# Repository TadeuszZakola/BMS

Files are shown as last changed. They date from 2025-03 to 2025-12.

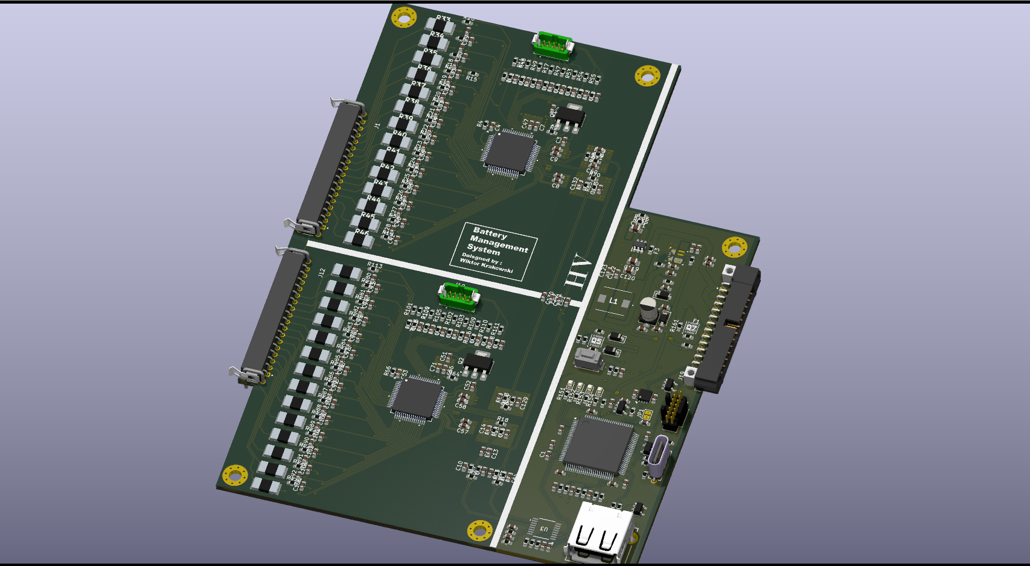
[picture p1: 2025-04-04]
bms.png

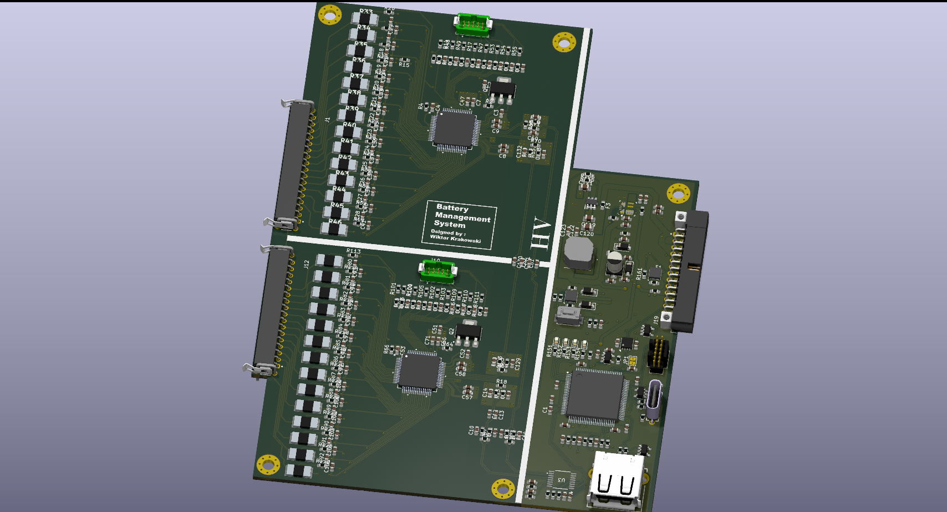
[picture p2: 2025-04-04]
bms2.png

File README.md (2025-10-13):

#Battery Management System  🔋⚡️

Welcome to the Battery Management System (BMS) project! 🚀 This open-source project combines cutting-edge hardware and software to deliver a robust, customizable solution for managing battery packs in applications like electric vehicles. With advanced monitoring, safety features, and seamless integration, this BMS ensures optimal battery performance and longevity. 🌱

🌟 Key Features

26 Individual Cell-Group Voltage Measurements ✅: Monitors voltage across 26 cell groups with high precision.

16 Temperature Sensors 🌡️: Provides comprehensive thermal monitoring to prevent overheating and ensure safe operation.

Cell Balancing 🔄: Actively balances cells to optimize capacity and extend battery lifespan.

Safety Relay 🔒: Isolates the battery pack during faults for enhanced safety.

Current Sensor ⚡: Enables real-time current monitoring and protection against overcurrent conditions.

CAN Bus 📊: Supports CAN communication for integration with external systems and data logging.

Advanced Safety Features 🛡️:

Over-voltage and under-voltage protection

Over-temperature shutdown

Current limiting via relay and BMS logic

Emergency cut-off for driver safety

Hardware & Software Integration 🛠️: Combines robust hardware (microcontroller, sensors, relays) with modular software for real-time monitoring and control.

User-Friendly Dashboard App 🖥️: Visualize battery metrics and configure settings through an intuitive interface.

CAN Integration: Supports CAN bus protocols for data transmission and external control.

Logging: Stores historical data for diagnostics and performance analysis.

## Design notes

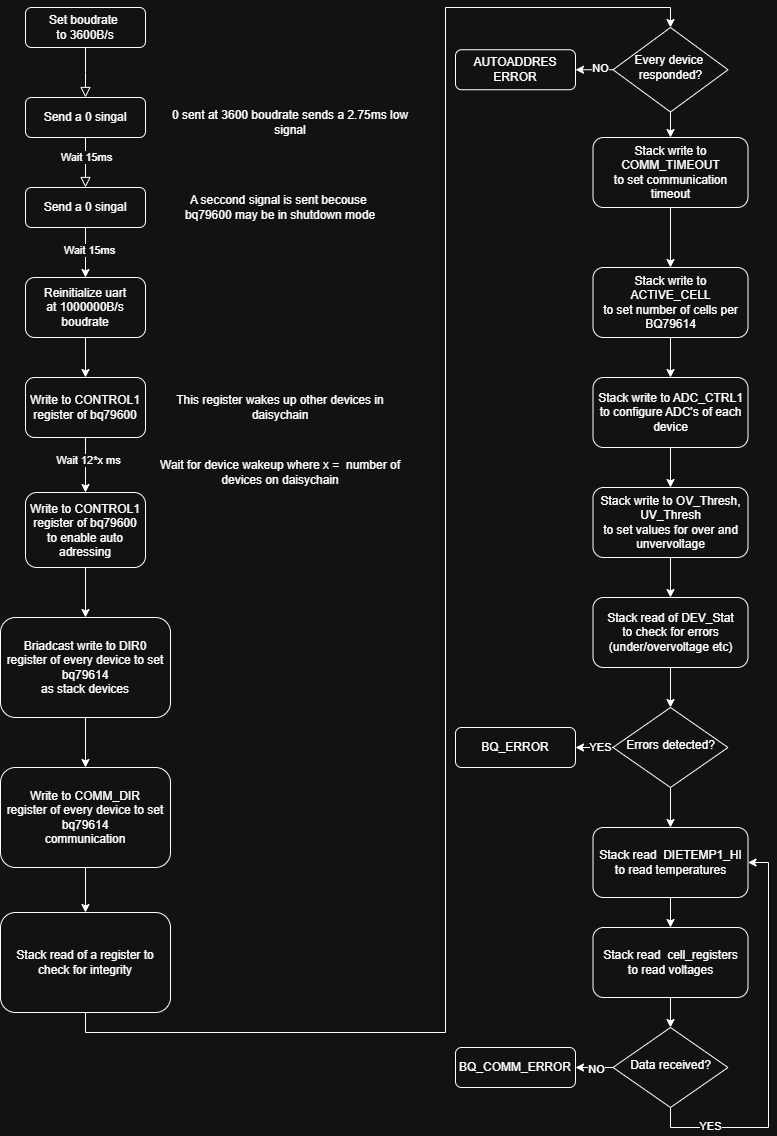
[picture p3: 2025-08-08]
Software/Software_diagrams/bq_task.png

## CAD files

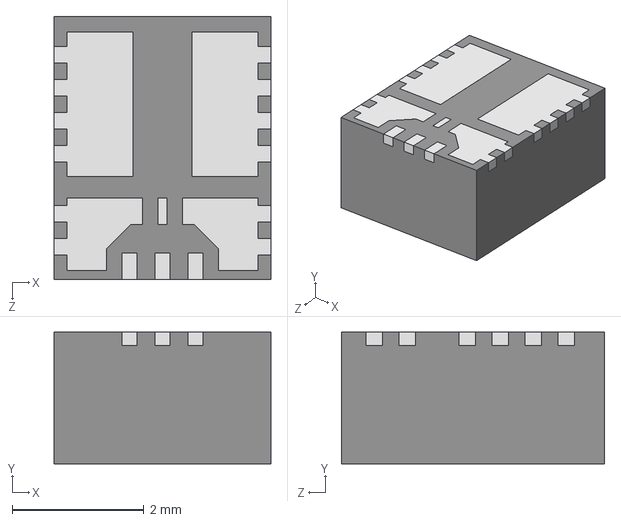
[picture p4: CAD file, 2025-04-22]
Hardware/include/model/TPSM863253RDXR.stp
3.30 x 2.00 x 4.00 mm

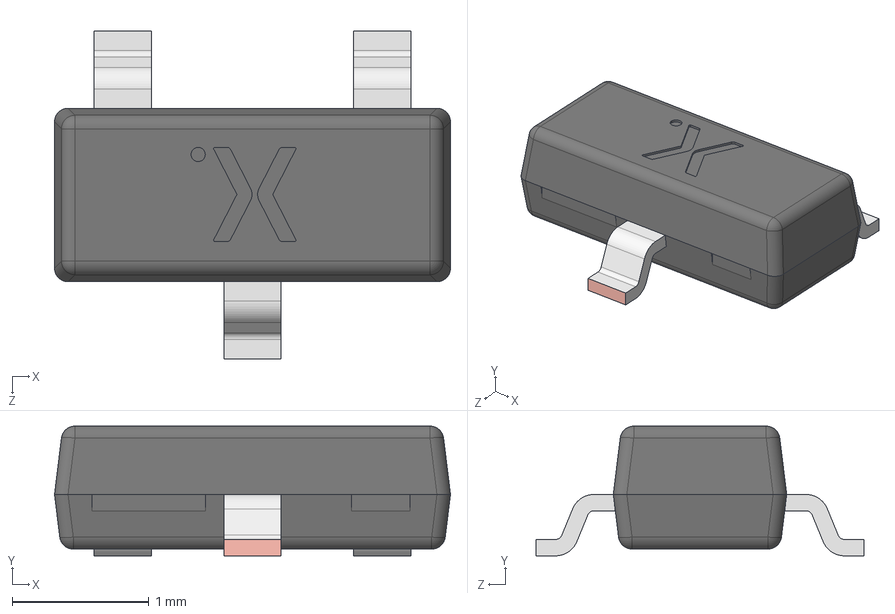
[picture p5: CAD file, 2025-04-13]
Hardware/include/model/PBSS8110T-QR.stp
2.90 x 0.95 x 2.40 mm
SOT23 lower body
SOT23 Lead x 3
SOT23 Upper body

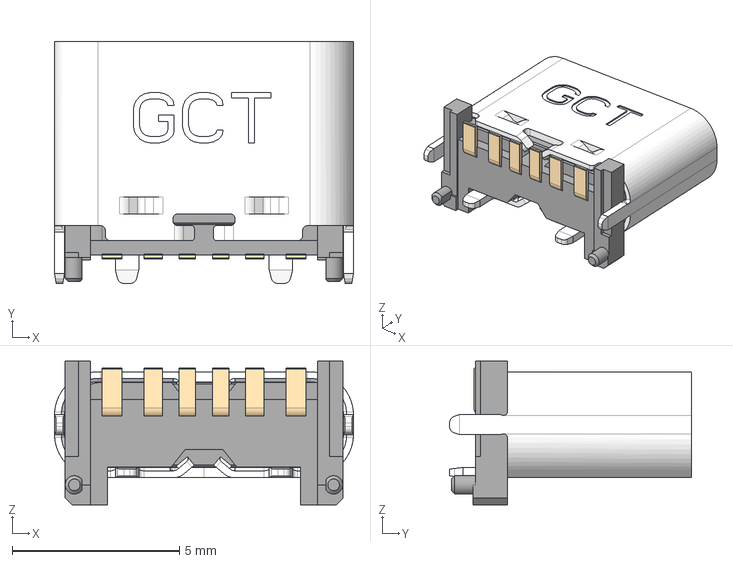
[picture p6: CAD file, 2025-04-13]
Hardware/include/model/USB4140-GF-0070-C.stp
8.94 x 7.23 x 4.30 mm
USB4140-GF-0070-C_PART2
USB4140-GF-0070-C_PART1

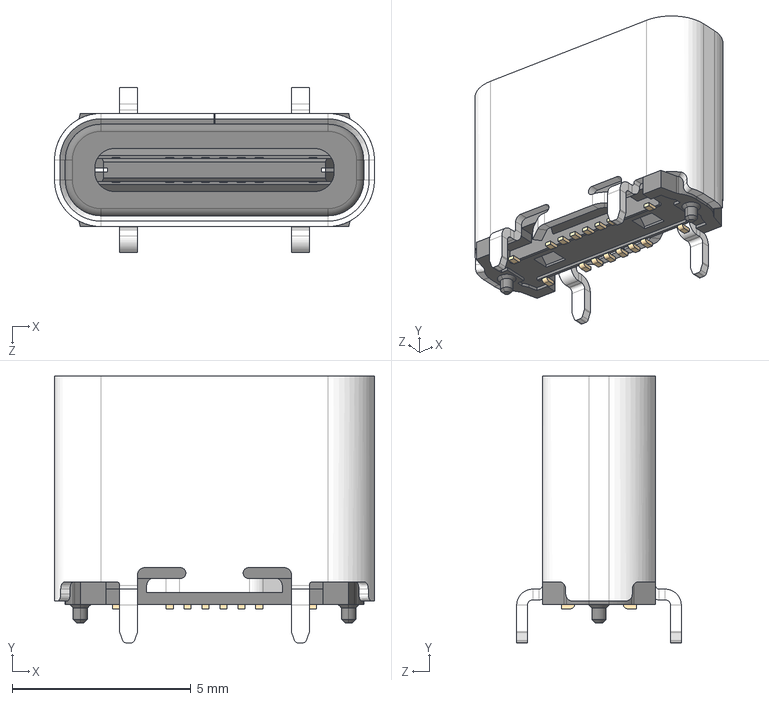
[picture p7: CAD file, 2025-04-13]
Hardware/include/model/USB4120-03-C.stp
8.94 x 7.45 x 4.60 mm

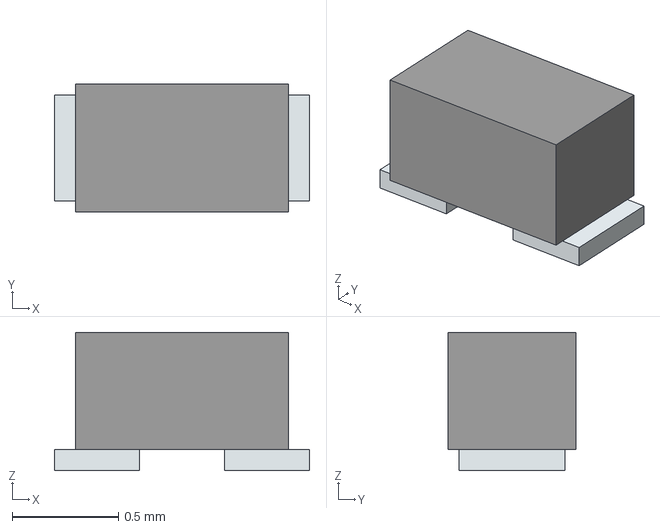
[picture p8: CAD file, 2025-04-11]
Hardware/include/model/ESDSB12VLB-TP.stp
1.20 x 0.6 x 0.65 mm
Pins

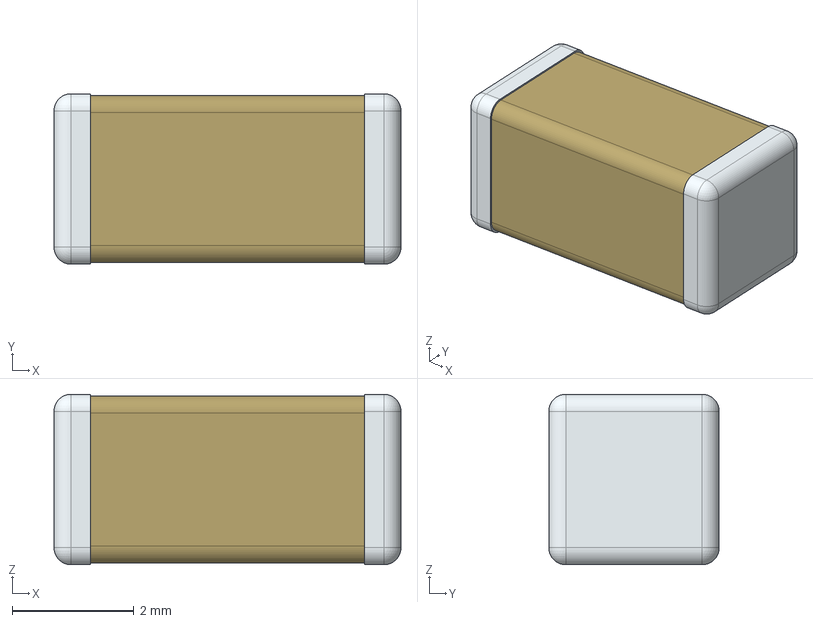
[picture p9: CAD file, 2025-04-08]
Hardware/include/model/S252B222K502CT.stp
5.70 x 2.80 x 2.80 mm

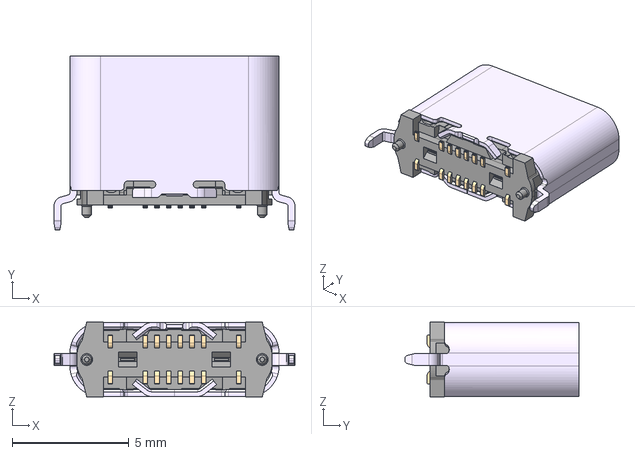
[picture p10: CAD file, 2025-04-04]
Hardware/include/model/usb4235-03-c.stp
10.3 x 7.45 x 3.20 mm

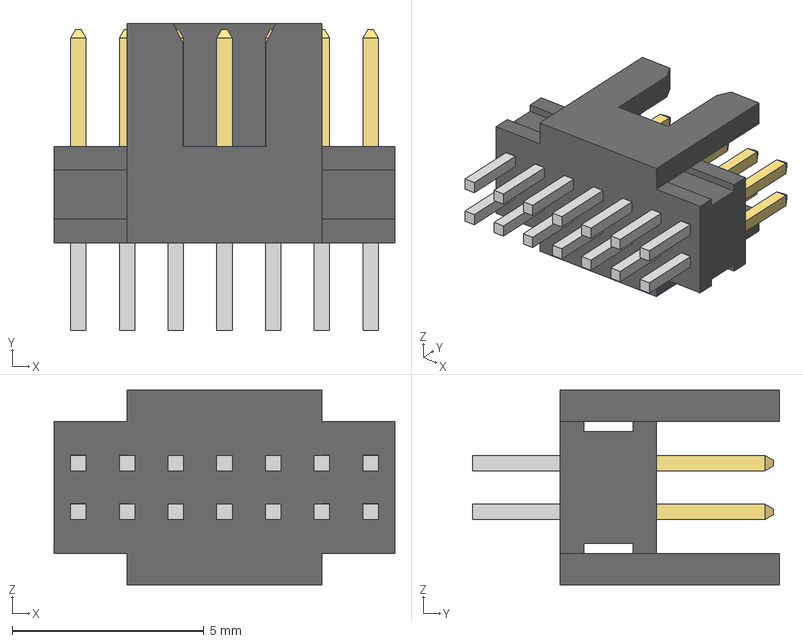
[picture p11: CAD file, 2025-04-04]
Hardware/include/model/FTSH-107-01-L-D-K.stp
8.89 x 8.00 x 5.08 mm
FTSH-107-01-L-D-K_body
FTSH-107-01-L-D-K_pins1
FTSH-107-01-L-D-K_pins2

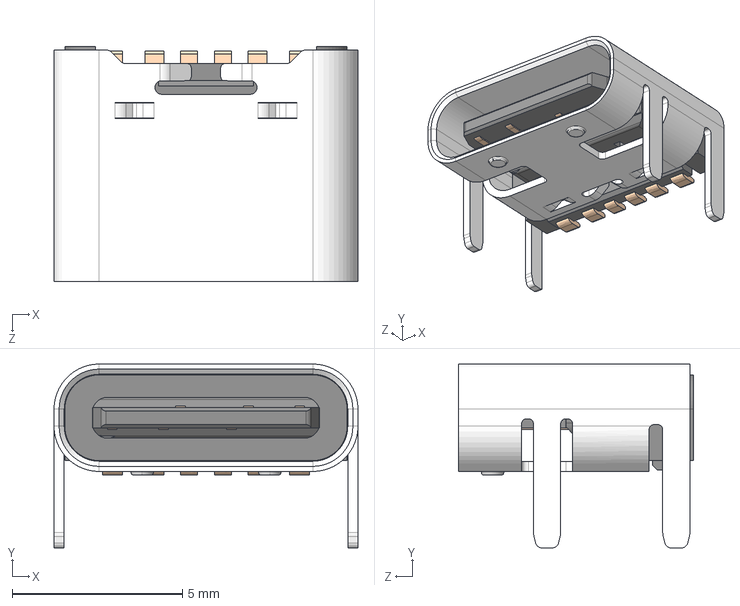
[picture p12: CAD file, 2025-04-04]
Hardware/include/model/USB4125-GF-A-0190.stp
8.94 x 5.41 x 6.90 mm

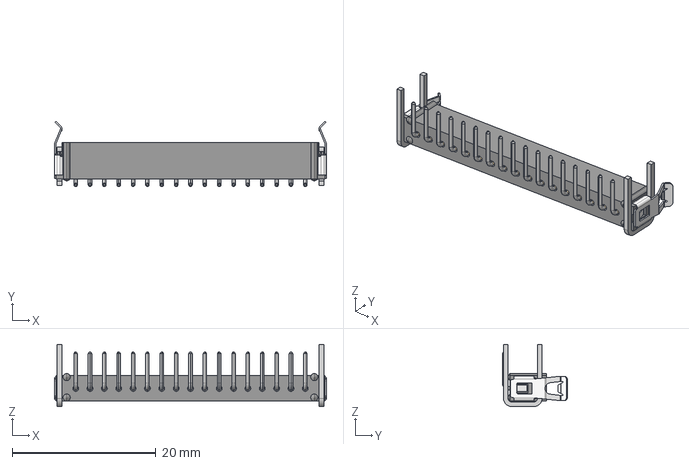
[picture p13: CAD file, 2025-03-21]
Hardware/include/model/b5743-117-m-l-1.stp
37.9 x 9.10 x 8.64 mm

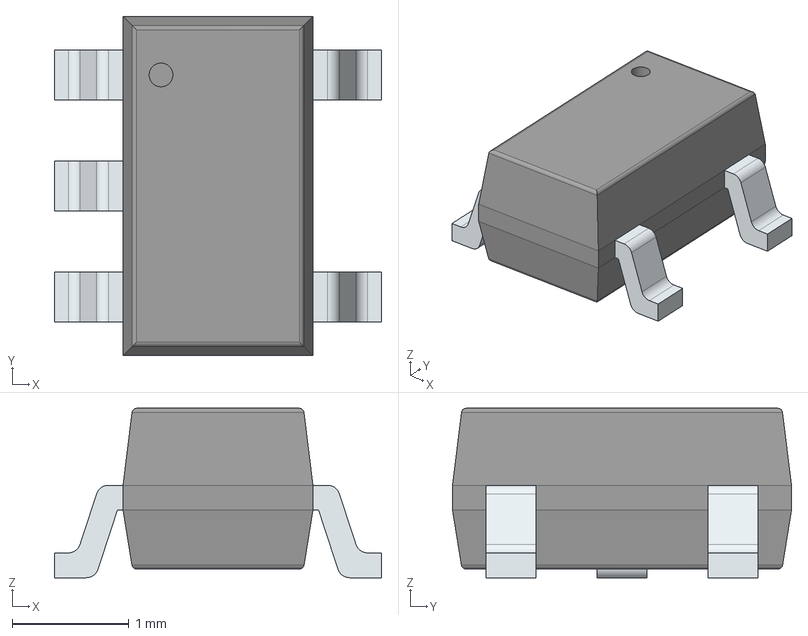
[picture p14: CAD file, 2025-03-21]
Hardware/include/model/ESDA5V3SC5.stp
2.80 x 2.90 x 1.45 mm
PinsArrayL
PinsArrayR

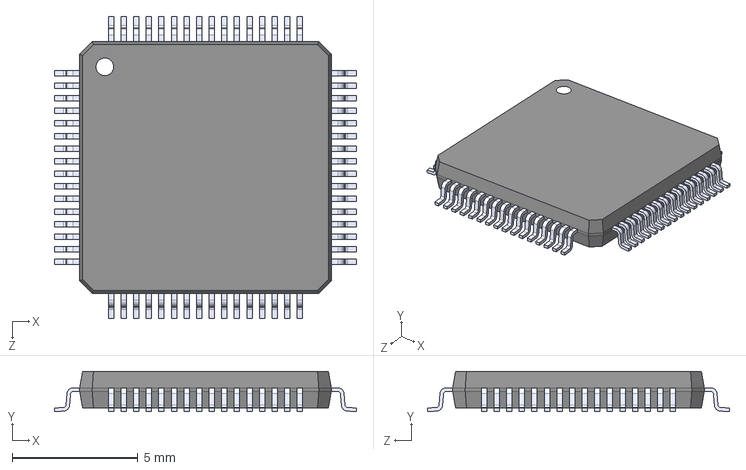
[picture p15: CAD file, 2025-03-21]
Hardware/include/model/STM32F405RGT6.step
12.0 x 1.60 x 12.0 mm

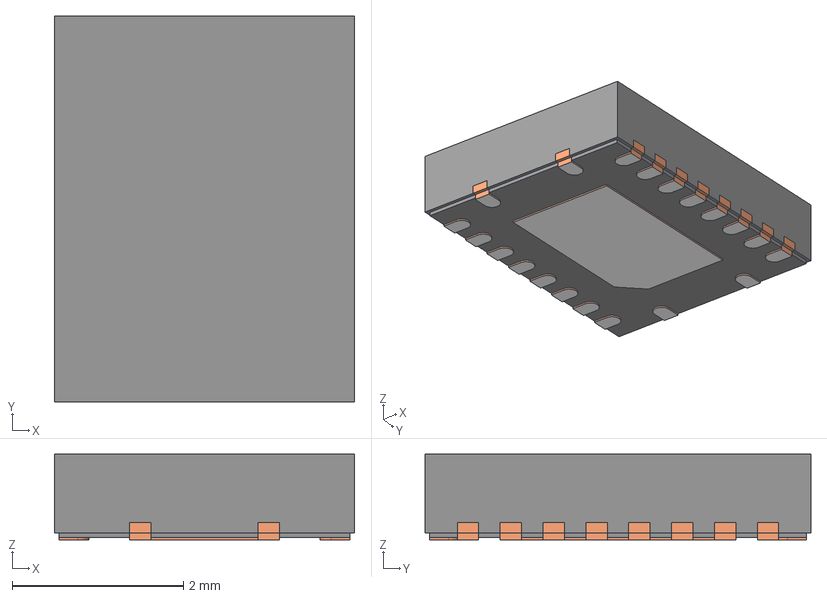
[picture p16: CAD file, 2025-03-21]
Hardware/include/model/LM5146RGYR.stp
3.50 x 4.50 x 1.00 mm
BODY-QFN_AF0
FRAME-RGY0020B_AF0
PIN1-ID

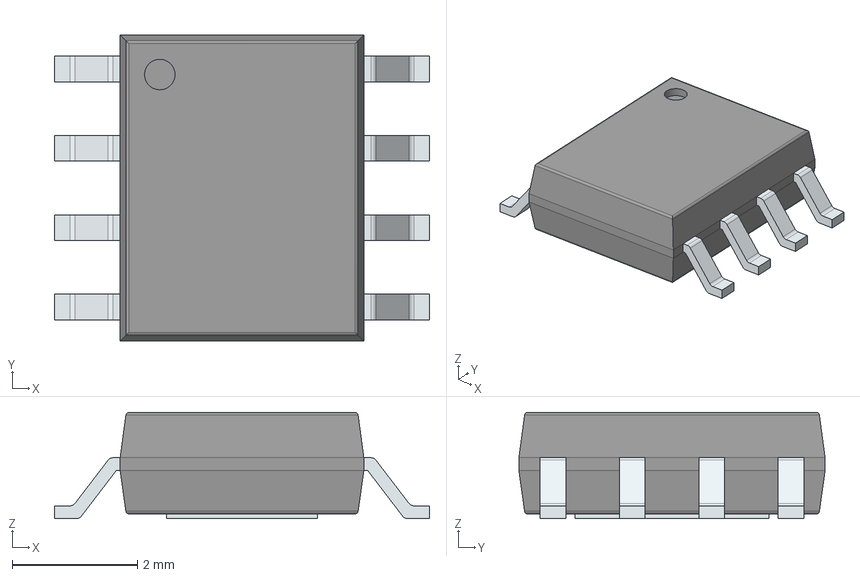
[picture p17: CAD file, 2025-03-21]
Hardware/include/model/LM5013DDAR.stp
6.00 x 4.90 x 1.70 mm
PinsArrayLR
ThermalPad

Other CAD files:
Hardware/include/model/CRM2512QFW-10R0ELF.stp
Hardware/include/model/SC59-3_1P5X2P9_ONS.step
Hardware/include/model/CLF7045NIT-3R3N-D.stp
Hardware/include/model/DMT6018LDR-7.stp
Hardware/include/model/147873-2.stp
Hardware/include/model/BQ79612PAPRQ1.step
Hardware/include/model/TPS563200DDCR.stp
Hardware/include/model/USB1046-GF-0190-L-B-A.stp
Hardware/include/model/bq79600.stp
Hardware/include/model/m80-5002642.stp
Hardware/include/model/m80-5002842.stp
Hardware/include/model/m80-5102642.stp
Hardware/include/model/m80-5402642.stp
Hardware/include/model/m80-8542042.stp

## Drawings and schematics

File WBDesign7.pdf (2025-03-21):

## WEBENCH ® Design Report

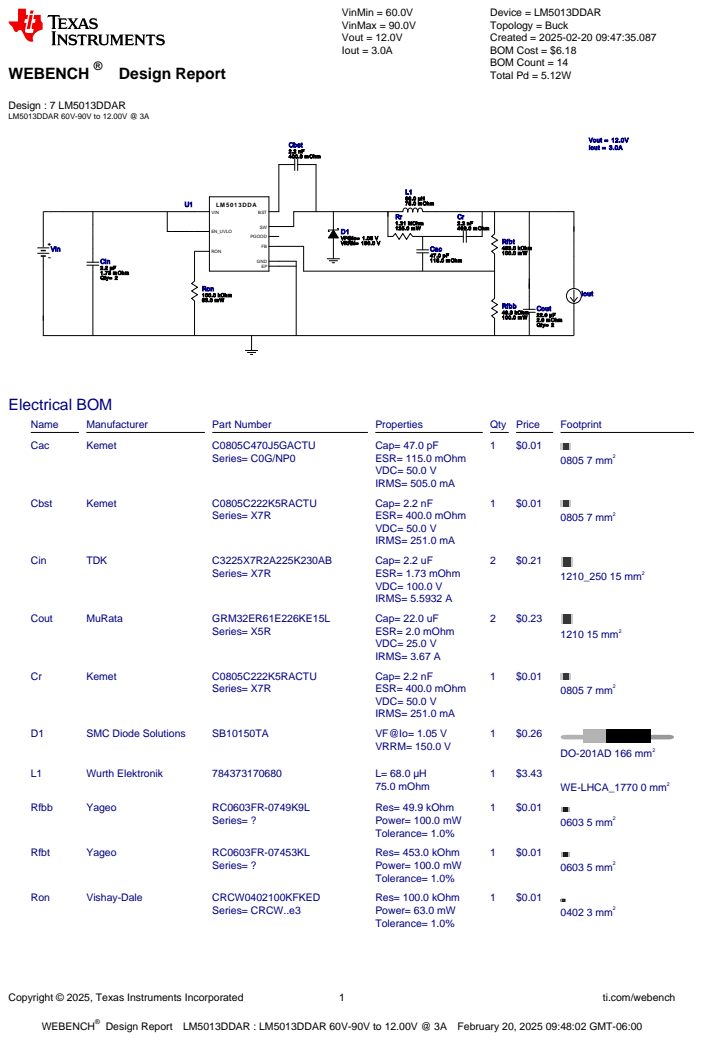
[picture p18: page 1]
Copyright © 2025, Texas Instruments Incorporated; ti.com/webench; WEBENCH®; Design : 7 LM5013DDAR LM5013DDAR 60V-90V to 12.00V @ 3A; VinMin = 60.0V VinMax = 90.0V Vout = 12.0V Iout = 3.0A; Device = LM5013DDAR Topology = Buck Created = 2025-02-20 09:47:35.087 BOM Cost = $6.18 BOM Count = 14 Total Pd = 5.12W; LM 5 0 1 3 DDA; GND; VIN; EN_UVLO; RON; PGOOD; BST; Cac 47.0 pF 115.0 m Ohm; Rr 1.21 MOhm 125.0 m W; Cr 2.2 nF 400.0 m Ohm; Cout 22.0 µF 2.0 m Ohm Qty= 2; L1 68.0 µH 75.0 m Ohm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

Design Report LM5013DDAR : LM5013DDAR 60V-90V to 12.00V @ 3A February 20, 2025 09:48:02 GMT-06:00

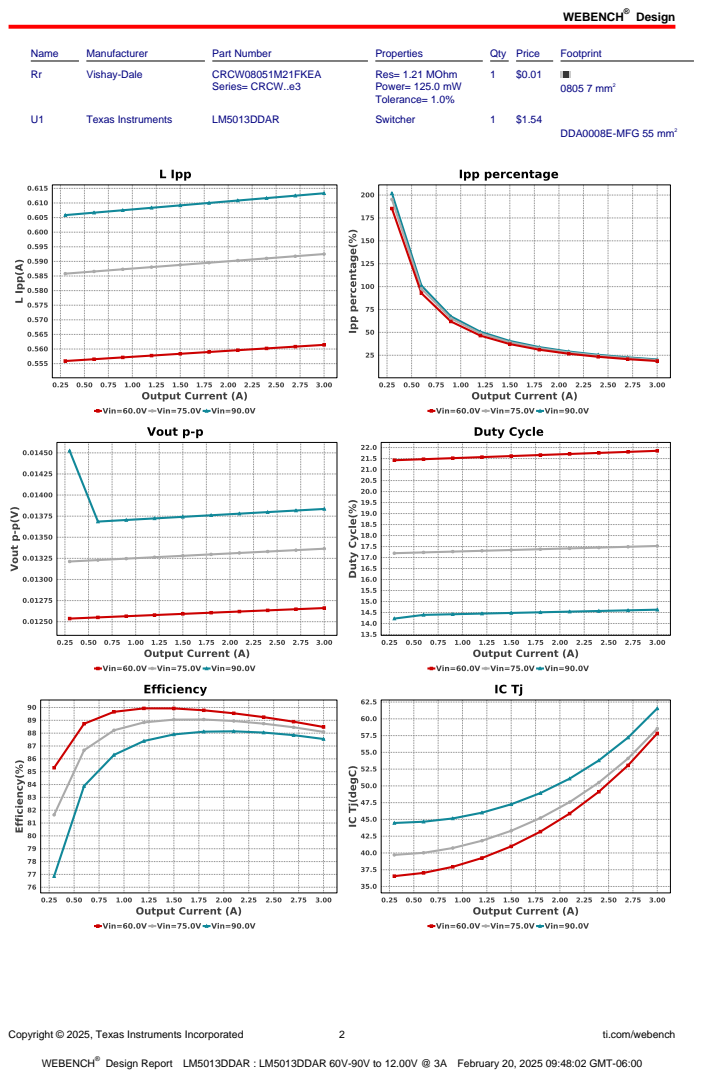
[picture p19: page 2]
Design; Copyright © 2025, Texas Instruments Incorporated; ti.com/webench; Name; Manufacturer; Part Number; Properties; Qty Price; Footprint; Vishay-Dale; CRCW08051M21FKEA; Series= CRCW..e3; Res= 1.21 MOhm Power= 125.0 mW Tolerance= 1.0%; 0805 7 mm²; Texas Instruments; LM5013DDAR; Switcher; DDA0008E-MFG 55 mm²

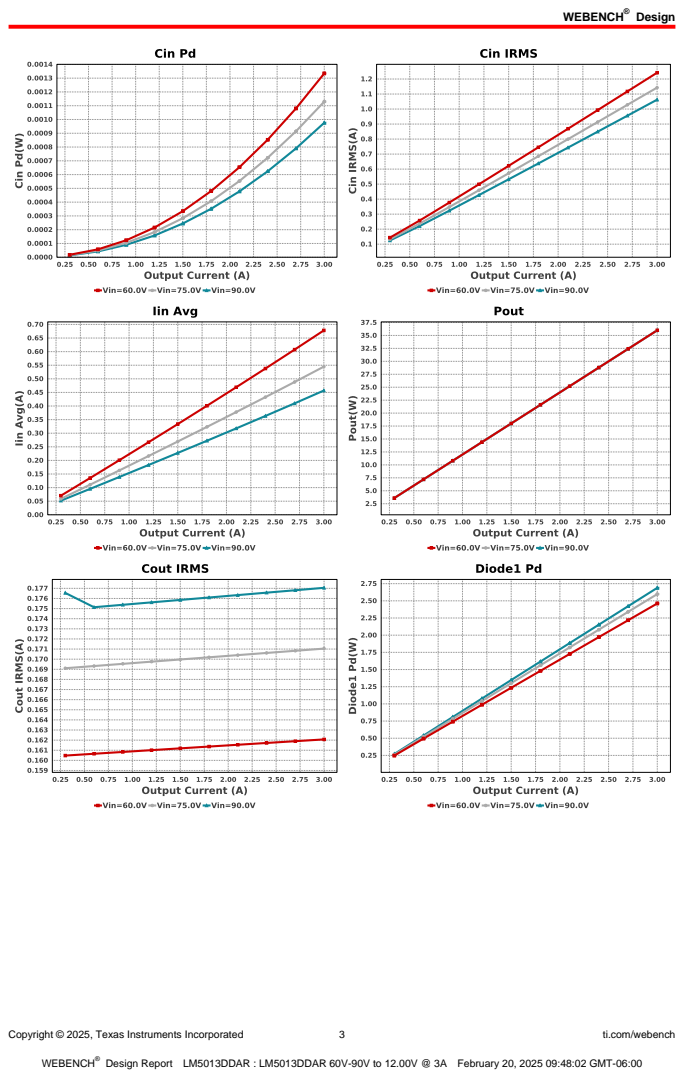
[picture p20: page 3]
Copyright © 2025, Texas Instruments Incorporated; ti.com/webench

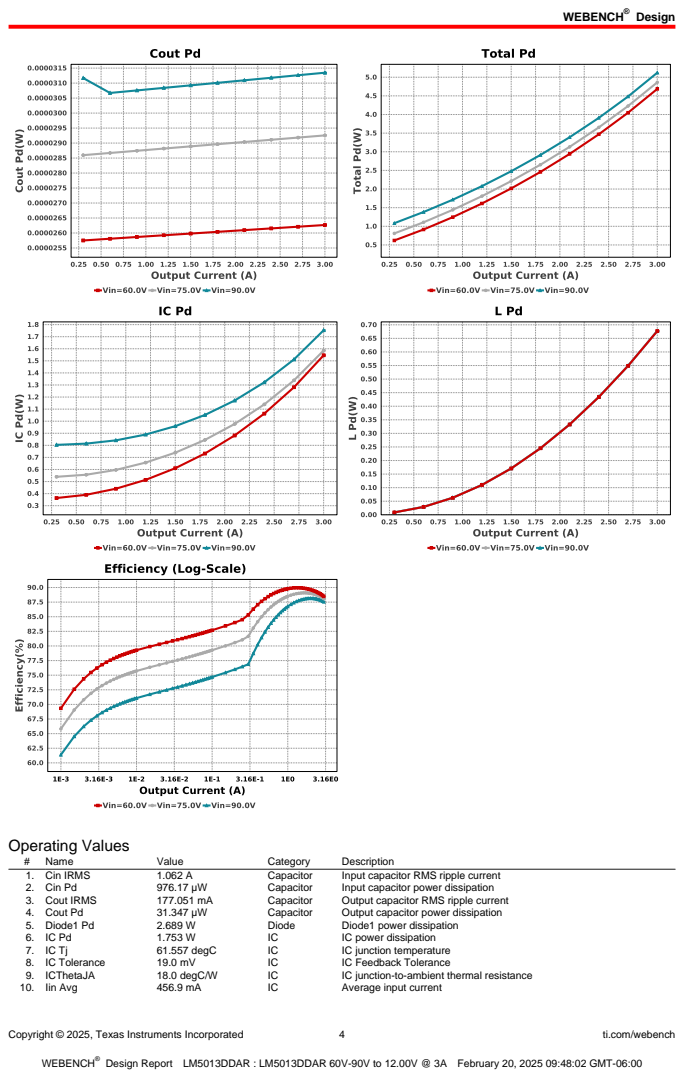
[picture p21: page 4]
Copyright © 2025, Texas Instruments Incorporated; ti.com/webench; Operating Values; Name; Value; Category; Description; 1. Cin IRMS; Capacitor; Input capacitor RMS ripple current; 2. Cin Pd; Input capacitor power dissipation; 3. Cout IRMS; Output capacitor RMS ripple current; 4. Cout Pd; Output capacitor power dissipation; 5. Diode1 Pd; Diode; Diode1 power dissipation; IC power dissipation; 61.557 degC; IC junction temperature; 8. IC Tolerance; IC Feedback Tolerance; 9. ICThetaJA; 18.0 degC/W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

Copyright © 2025, Texas Instruments Incorporated | 5 | ti.com/webench
# | Name | Value | Category | Description

11. Ipp percentage | 20.444 % | Inductor | Inductor ripple current percentage (with respect to average inductor
| | | | current)
12. L Ipp | 613.32 mA | Inductor | Peak-to-peak inductor ripple current
13. L Pd | 677.35 mW | Inductor | Inductor power dissipation
14. Cin Pd | 976.17 µW | Power | Input capacitor power dissipation
15. Cout Pd | 31.347 µW | Power | Output capacitor power dissipation
16. Diode1 Pd | 2.689 W | Power | Diode1 power dissipation
17. IC Pd | 1.753 W | Power | IC power dissipation
18. L Pd | 677.35 mW | Power | Inductor power dissipation
19. Total Pd | 5.121 W | Power | Total Power Dissipation
20. BOM Count | 14 | System
| | | Information | Total Design BOM count
21. Duty Cycle | 14.628 % | System
| | | Information | Duty cycle
22. Efficiency | 87.546 % | System
| | | Information | Steady state efficiency
23. FootPrint | 720.0 mm² | System
| | | Information | Total Foot Print Area of BOM components
24. Frequency | 271.739 kHz | System
| | | Information | Switching frequency
25. Iout | 3.0 A | System
| | | Information | Iout operating point
26. Mode | CCM | System
| | | Information | Conduction Mode
27. Pout | 36.0 W | System
| | | Information | Total output power
28. Total BOM | $6.18 | System
| | | Information | Total BOM Cost
29. Vin | 90.0 V | System
| | | Information | Vin operating point
30. Vout | 12.0 V | System
| | | Information | Operational Output Voltage
31. Vout Actual | 12.094 V | System
| | | Information | Vout Actual calculated based on selected voltage divider resistors
32. Vout Tolerance | 3.432 % | System
| | | Information | Vout Tolerance based on IC Tolerance (no load) and voltage divider resistors if applicable
33. Vout p-p | 13.835 mV | System
| | | Information | Peak-to-peak output ripple voltage

## Design Inputs

Name | Value | Description
Iout | 3.0 | Maximum Output Current
VinMax | 90.0 | Maximum input voltage
VinMin | 60.0 | Minimum input voltage
Vout | 12.0 | Output Voltage
| base_pn | | LM5013 | Base Product Number
source | DC | Input Source Type
Ta | 30.0 | Ambient temperature


Copyright © 2025, Texas Instruments Incorporated | 6 | ti.com/webench

## Assembly
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

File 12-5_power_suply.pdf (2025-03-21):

## WEBENCH ® Design Report

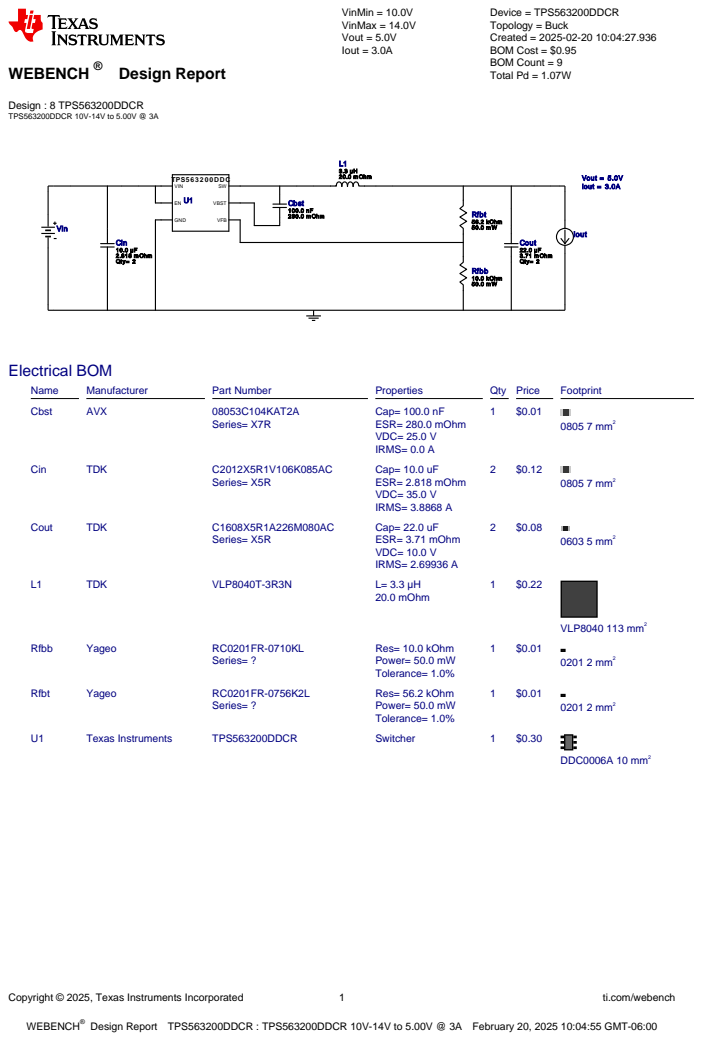
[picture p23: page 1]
Copyright © 2025, Texas Instruments Incorporated; ti.com/webench; WEBENCH®; Design : 8 TPS563200DDCR TPS563200DDCR 10V-14V to 5.00V @ 3A; VinMin = 10.0V VinMax = 14.0V Vout = 5.0V Iout = 3.0A; Device = TPS563200DDCR Topology = Buck Created = 2025-02-20 10:04:27.936 BOM Cost = $0.95 BOM Count = 9 Total Pd = 1.07W; Rfbt 56.2 kOhm 50.0 m W; Cout 22.0 µF 3.71 m Ohm Qty= 2; Vout = 5.0V Iout = 3.0A; L1 3.3 µH 20.0 m Ohm; Rfbb 10.0 kOhm 50.0 m W; Cin 10.0 µF 2.818 m Ohm Qty= 2; TPS5 6 3 2 0 0 DDC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

Design Report TPS563200DDCR : TPS563200DDCR 10V-14V to 5.00V @ 3A February 20, 2025 10:04:55 GMT-06:00

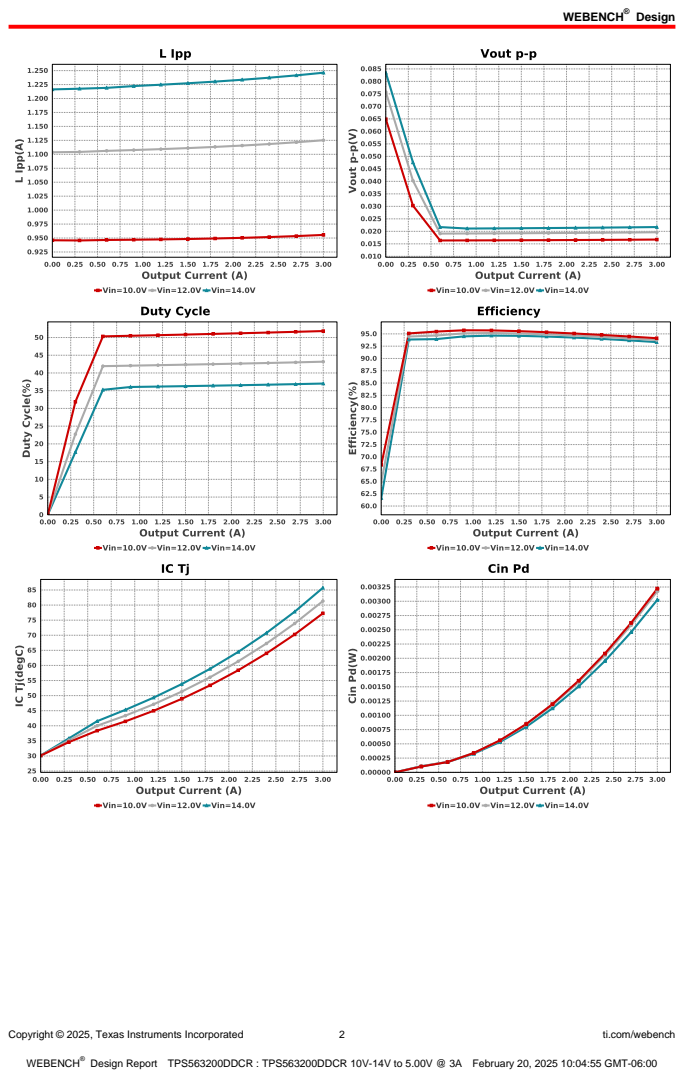
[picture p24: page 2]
Design; Copyright © 2025, Texas Instruments Incorporated; ti.com/webench

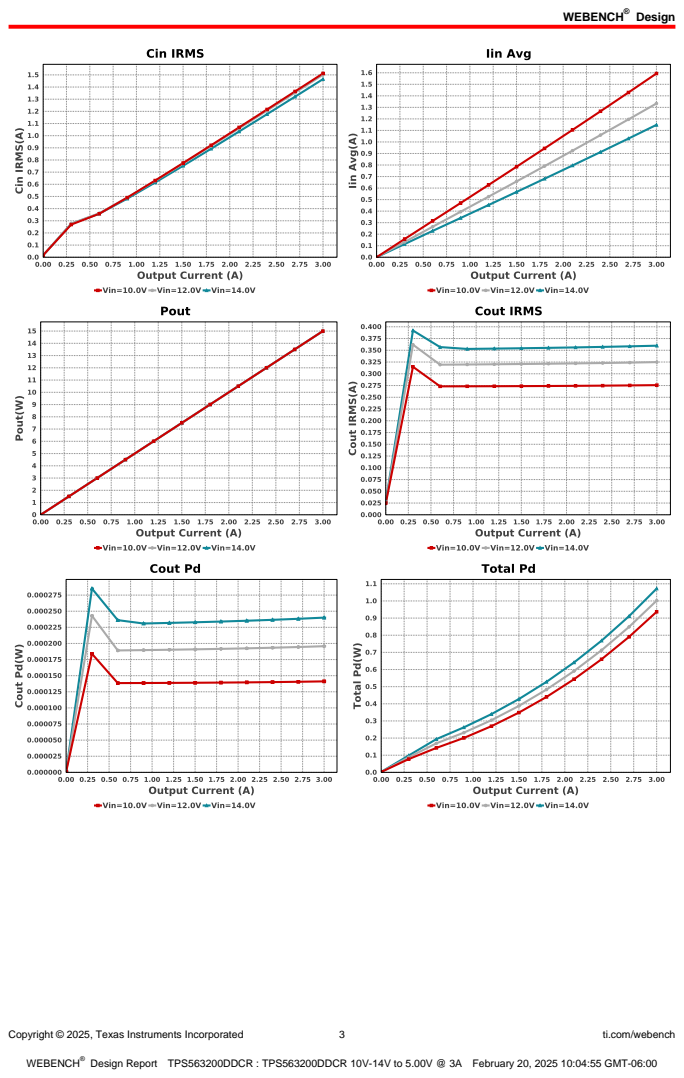
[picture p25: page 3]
Copyright © 2025, Texas Instruments Incorporated; ti.com/webench

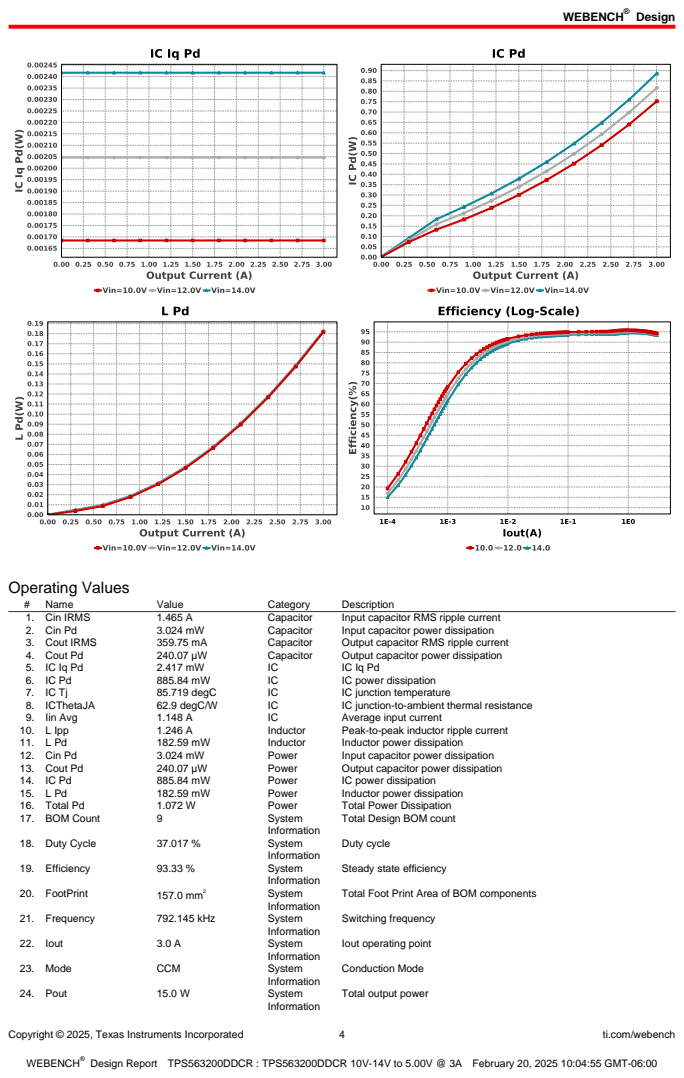
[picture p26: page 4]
Copyright © 2025, Texas Instruments Incorporated; ti.com/webench; Operating Values; Name; Value; Category; Description; 1. Cin IRMS; Capacitor; Input capacitor RMS ripple current; 2. Cin Pd; Input capacitor power dissipation; 3. Cout IRMS; Output capacitor RMS ripple current; 4. Cout Pd; Output capacitor power dissipation; IC power dissipation; 85.719 degC; IC junction temperature; 8. ICThetaJA; 62.9 degC/W; IC junction-to-ambient thermal resistance; 9. Iin Avg; Average input current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

Total Design BOM count

Steady state efficiency

Total Foot Print Area of BOM components

Iout operating point

Total output power

Copyright © 2025, Texas Instruments Incorporated | 5 | ti.com/webench
# | Name | Value | Category | Description

25. Total BOM | $0.95 | System
| | | Information | Total BOM Cost
26. Vin | 14.0 V | System
| | | Information | Vin operating point
27. Vout | 5.0 V | System
| | | Information | Operational Output Voltage
28. Vout Actual | 5.031 V | System
| | | Information | Vout Actual calculated based on selected voltage divider resistors
29. Vout Tolerance | 3.053 % | System
| | | Information | Vout Tolerance based on IC Tolerance (no load) and voltage divider resistors if applicable
30. Vout p-p | 21.718 mV | System
| | | Information | Peak-to-peak output ripple voltage

## Design Inputs

Name | Value | Description
Iout | 3.0 | Maximum Output Current
VinMax | 14.0 | Maximum input voltage
VinMin | 10.0 | Minimum input voltage
Vout | 5.0 | Output Voltage
| base_pn | | TPS563200 | Base Product Number
source | DC | Input Source Type
Ta | 30.0 | Ambient temperature


Copyright © 2025, Texas Instruments Incorporated | 6 | ti.com/webench

## Assembly

## Component Testing

Some published data on components in datasheets such as Capacitor ESR and Inductor DC resistance is based on conservative values that will guarantee that the components always exceed the specification. For design purposes it is usually better to work with typical values. Since this data is not always available it is a good practice to measure the Capacitance and ESR values of Cin and Cout, and the inductance and DC resistance of L1 before assembly of the board. Any large discrepancies in values should be electrically simulated in WEBENCH to check for instabilities and thermally simulated in WebTHERM to make sure critical temperatures are not exceeded.

## Soldering Component to Board

If board assembly is done in house it is best to tack down one terminal of a component on the board then solder the other terminal. For surface mount parts with large tabs, such as the DPAK, the tab on the back of the package should be pre-tinned with solder, then tacked into place by one of the pins. To solder the tab town to the board place the iron down on the board while resting against the tab, heating both surfaces simultaneously. Apply light pressure to the top of the plastic case until the solder flows around the part and the part is flush with the PCB. If the solder is not flowing around the board you may need a higher wattage iron (generally 25W to 30W is enough).
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

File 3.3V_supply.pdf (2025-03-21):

## WEBENCH ® Design Report

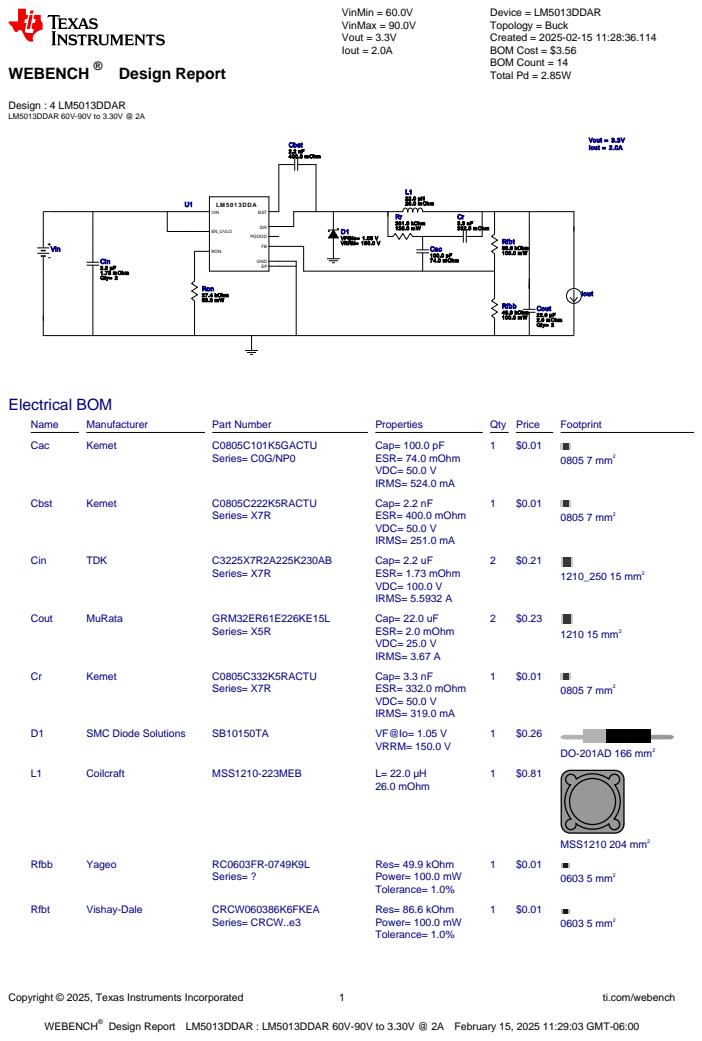
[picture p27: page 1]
Copyright © 2025, Texas Instruments Incorporated; ti.com/webench; WEBENCH®; Design : 4 LM5013DDAR LM5013DDAR 60V-90V to 3.30V @ 2A; VinMin = 60.0V VinMax = 90.0V Vout = 3.3V Iout = 2.0A; Device = LM5013DDAR Topology = Buck Created = 2025-02-15 11:28:36.114 BOM Cost = $3.56 BOM Count = 14 Total Pd = 2.85W; LM 5 0 1 3 DDA; GND; VIN; EN_UVLO; RON; PGOOD; BST; Cac 100.0 pF 74.0 m Ohm; Rr 261.0 kOhm 125.0 m W; Cr 3.3 nF 332.0 m Ohm; Cout 22.0 µF 2.0 m Ohm Qty= 2; L1 22.0 µH 26.0 m Ohm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

Design Report LM5013DDAR : LM5013DDAR 60V-90V to 3.30V @ 2A February 15, 2025 11:29:03 GMT-06:00

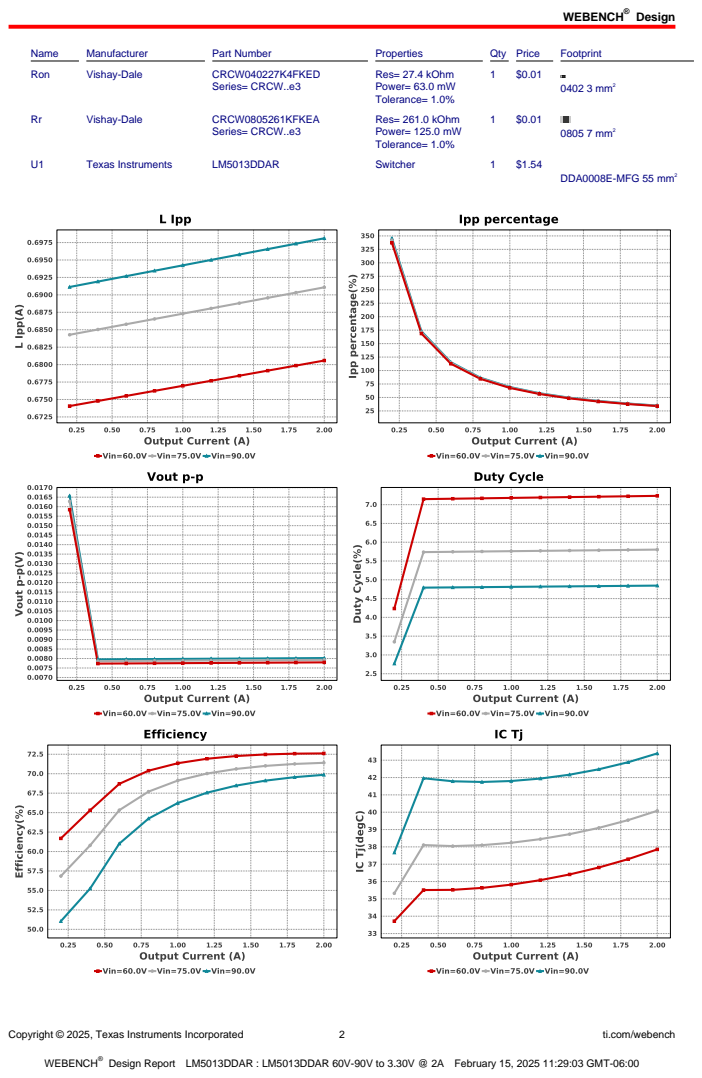
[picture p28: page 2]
Design; Copyright © 2025, Texas Instruments Incorporated; ti.com/webench; Name; Manufacturer; Part Number; Properties; Qty Price; Footprint; Ron; Vishay-Dale; CRCW040227K4FKED; Series= CRCW..e3; Res= 27.4 kOhm Power= 63.0 mW Tolerance= 1.0%; 0402 3 mm²; CRCW0805261KFKEA; Res= 261.0 kOhm Power= 125.0 mW Tolerance= 1.0%; 0805 7 mm²; Texas Instruments; LM5013DDAR; Switcher; DDA0008E-MFG 55 mm²

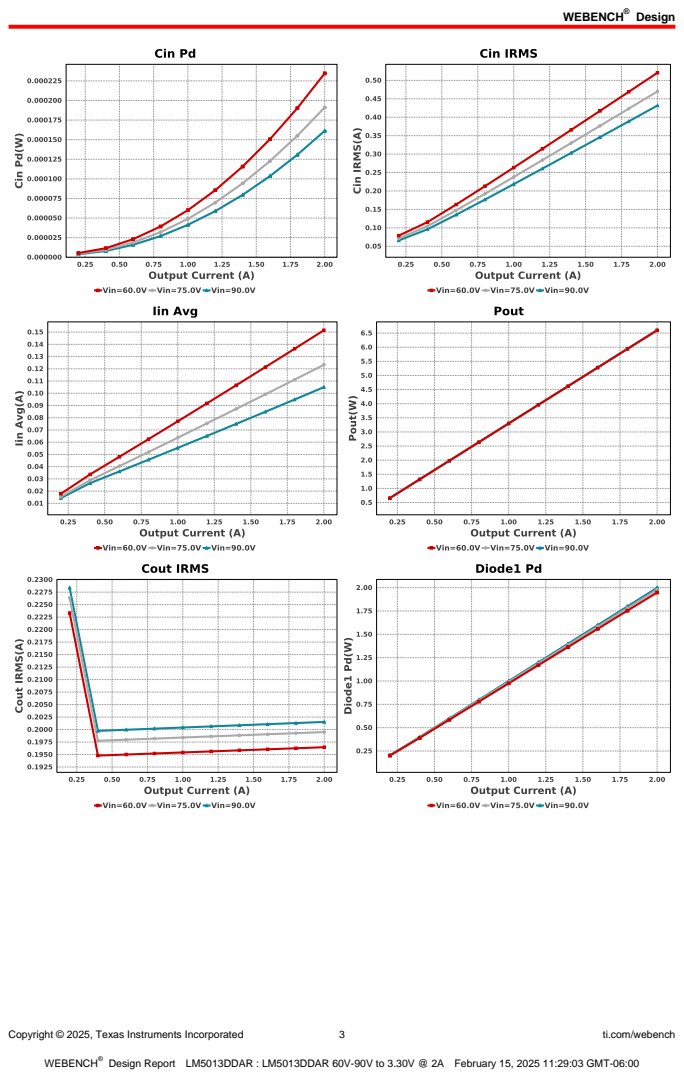
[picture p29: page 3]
Copyright © 2025, Texas Instruments Incorporated; ti.com/webench

Copyright © 2025, Texas Instruments Incorporated; ti.com/webench; Operating Values; Name; Value; Category; Description; 1. Cin IRMS; Capacitor; Input capacitor RMS ripple current; 2. Cin Pd; Input capacitor power dissipation; 3. Cout IRMS; Output capacitor RMS ripple current; 4. Cout Pd; Output capacitor power dissipation; 5. Diode1 Pd; Diode; Diode1 power dissipation; IC power dissipation; 43.392 degC; IC junction temperature; 8. IC Tolerance; IC Feedback Tolerance; 9. ICThetaJA; 18.0 degC/W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

Copyright © 2025, Texas Instruments Incorporated | 5 | ti.com/webench
# | Name | Value | Category | Description

11. Ipp percentage | 34.905 % | Inductor | Inductor ripple current percentage (with respect to average inductor
| | | | current)
12. L Ipp | 698.11 mA | Inductor | Peak-to-peak inductor ripple current
13. L Pd | 105.06 mW | Inductor | Inductor power dissipation
14. Cin Pd | 161.23 µW | Power | Input capacitor power dissipation
15. Cout Pd | 40.613 µW | Power | Output capacitor power dissipation
16. Diode1 Pd | 1.998 W | Power | Diode1 power dissipation
17. IC Pd | 743.98 mW | Power | IC power dissipation
18. L Pd | 105.06 mW | Power | Inductor power dissipation
19. Total Pd | 2.848 W | Power | Total Power Dissipation
20. BOM Count | 14 | System
| | | Information | Total Design BOM count
21. Duty Cycle | 4.845 % | System
| | | Information | Duty cycle
22. Efficiency | 69.859 % | System
| | | Information | Steady state efficiency
23. FootPrint | 524.0 mm² | System
| | | Information | Total Foot Print Area of BOM components
24. Frequency | 272.731 kHz | System
| | | Information | Switching frequency
25. Iout | 2.0 A | System
| | | Information | Iout operating point
26. Mode | CCM | System
| | | Information | Conduction Mode
27. Pout | 6.6 W | System
| | | Information | Total output power
28. Total BOM | $3.56 | System
| | | Information | Total BOM Cost
29. Vin | 90.0 V | System
| | | Information | Vin operating point
30. Vout | 3.3 V | System
| | | Information | Operational Output Voltage
31. Vout Actual | 3.283 V | System
| | | Information | Vout Actual calculated based on selected voltage divider resistors
32. Vout Tolerance | 2.885 % | System
| | | Information | Vout Tolerance based on IC Tolerance (no load) and voltage divider resistors if applicable
33. Vout p-p | 8.024 mV | System
| | | Information | Peak-to-peak output ripple voltage

## Design Inputs

Name | Value | Description
Iout | 2.0 | Maximum Output Current
VinMax | 90.0 | Maximum input voltage
VinMin | 60.0 | Minimum input voltage
Vout | 3.3 | Output Voltage
| base_pn | | LM5013 | Base Product Number
source | DC | Input Source Type
Ta | 30.0 | Ambient temperature


Copyright © 2025, Texas Instruments Incorporated | 6 | ti.com/webench

## Assembly
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

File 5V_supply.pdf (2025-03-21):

## WEBENCH ® Design Report

Copyright © 2025, Texas Instruments Incorporated; ti.com/webench; WEBENCH®; Design : 6 LM5013DDAR LM5013DDAR 60V-90V to 5.00V @ 2A; VinMin = 60.0V VinMax = 90.0V Vout = 5.0V Iout = 2.0A; Device = LM5013DDAR Topology = Buck Created = 2025-02-15 12:24:38.412 BOM Cost = $3.62 BOM Count = 14 Total Pd = 2.89W; LM 5 0 1 3 DDA; GND; VIN; EN_UVLO; RON; PGOOD; BST; Cac 100.0 pF 74.0 m Ohm; Rr 374.0 kOhm 125.0 m W; Cr 3.3 nF 332.0 m Ohm; Cout 22.0 µF 2.0 m Ohm Qty= 2; L1 33.0 µH 33.0 m Ohm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

Design Report LM5013DDAR : LM5013DDAR 60V-90V to 5.00V @ 2A February 15, 2025 12:26:09 GMT-06:00

Design; Copyright © 2025, Texas Instruments Incorporated; ti.com/webench; Name; Manufacturer; Part Number; Properties; Qty Price; Footprint; Ron; Vishay-Dale; CRCW040241K2FKED; Series= CRCW..e3; Res= 41.2 kOhm Power= 63.0 mW Tolerance= 1.0%; 0402 3 mm²; Panasonic; ERJ-6ENF3743V; Series= ERJ-6E; Res= 374.0 kOhm Power= 125.0 mW Tolerance= 1.0%; 0805 7 mm²; Texas Instruments; LM5013DDAR; Switcher; DDA0008E-MFG 55 mm²

Copyright © 2025, Texas Instruments Incorporated; ti.com/webench

Copyright © 2025, Texas Instruments Incorporated; ti.com/webench; Operating Values; Name; Value; Category; Description; 1. Cin IRMS; Capacitor; Input capacitor RMS ripple current; 2. Cin Pd; Input capacitor power dissipation; 3. Cout IRMS; Output capacitor RMS ripple current; 4. Cout Pd; Output capacitor power dissipation; 5. Diode1 Pd; Diode; Diode1 power dissipation; IC power dissipation; 44.326 degC; IC junction temperature; 8. IC Tolerance; IC Feedback Tolerance; 9. ICThetaJA; 18.0 degC/W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

Copyright © 2025, Texas Instruments Incorporated | 5 | ti.com/webench
# | Name | Value | Category | Description

11. Ipp percentage | 31.449 % | Inductor | Inductor ripple current percentage (with respect to average inductor
| | | | current)
12. L Ipp | 628.99 mA | Inductor | Peak-to-peak inductor ripple current
13. L Pd | 133.09 mW | Inductor | Inductor power dissipation
14. Cin Pd | 219.16 µW | Power | Input capacitor power dissipation
15. Cout Pd | 32.969 µW | Power | Output capacitor power dissipation
16. Diode1 Pd | 1.959 W | Power | Diode1 power dissipation
17. IC Pd | 795.89 mW | Power | IC power dissipation
18. L Pd | 133.09 mW | Power | Inductor power dissipation
19. Total Pd | 2.888 W | Power | Total Power Dissipation
20. BOM Count | 14 | System
| | | Information | Total Design BOM count
21. Duty Cycle | 6.732 % | System
| | | Information | Duty cycle
22. Efficiency | 77.592 % | System
| | | Information | Steady state efficiency
23. FootPrint | 612.0 mm² | System
| | | Information | Total Foot Print Area of BOM components
24. Frequency | 274.817 kHz | System
| | | Information | Switching frequency
25. Iout | 2.0 A | System
| | | Information | Iout operating point
26. Mode | CCM | System
| | | Information | Conduction Mode
27. Pout | 10.0 W | System
| | | Information | Total output power
28. Total BOM | $3.62 | System
| | | Information | Total BOM Cost
29. Vin | 90.0 V | System
| | | Information | Vin operating point
30. Vout | 5.0 V | System
| | | Information | Operational Output Voltage
31. Vout Actual | 5.0 V | System
| | | Information | Vout Actual calculated based on selected voltage divider resistors
32. Vout Tolerance | 3.143 % | System
| | | Information | Vout Tolerance based on IC Tolerance (no load) and voltage divider resistors if applicable
33. Vout p-p | 8.003 mV | System
| | | Information | Peak-to-peak output ripple voltage

## Design Inputs

Name | Value | Description
Iout | 2.0 | Maximum Output Current
VinMax | 90.0 | Maximum input voltage
VinMin | 60.0 | Minimum input voltage
Vout | 5.0 | Output Voltage
| base_pn | | LM5013 | Base Product Number
source | DC | Input Source Type
Ta | 30.0 | Ambient temperature


Copyright © 2025, Texas Instruments Incorporated | 6 | ti.com/webench

## Assembly
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

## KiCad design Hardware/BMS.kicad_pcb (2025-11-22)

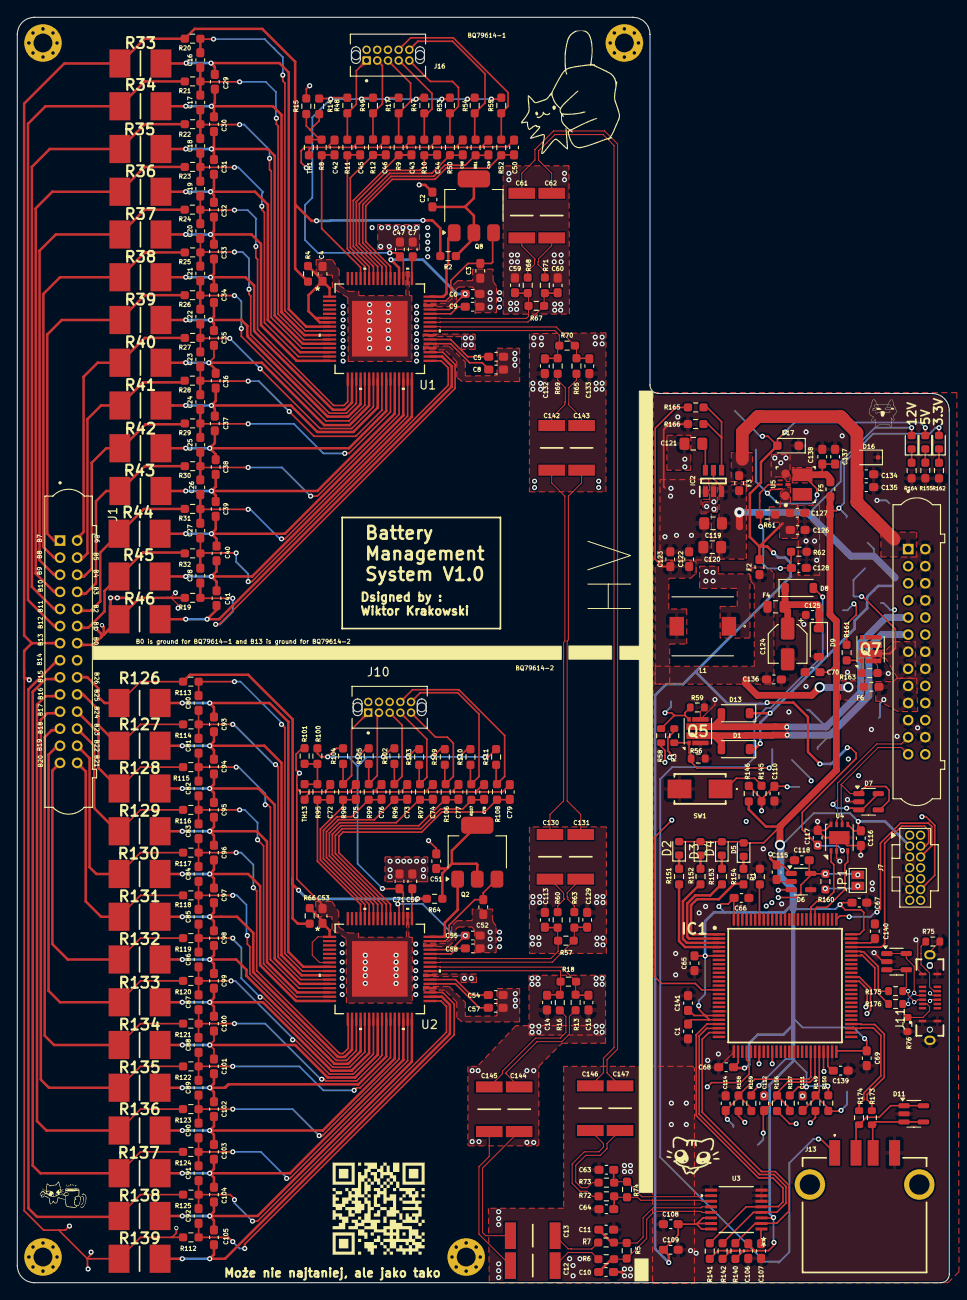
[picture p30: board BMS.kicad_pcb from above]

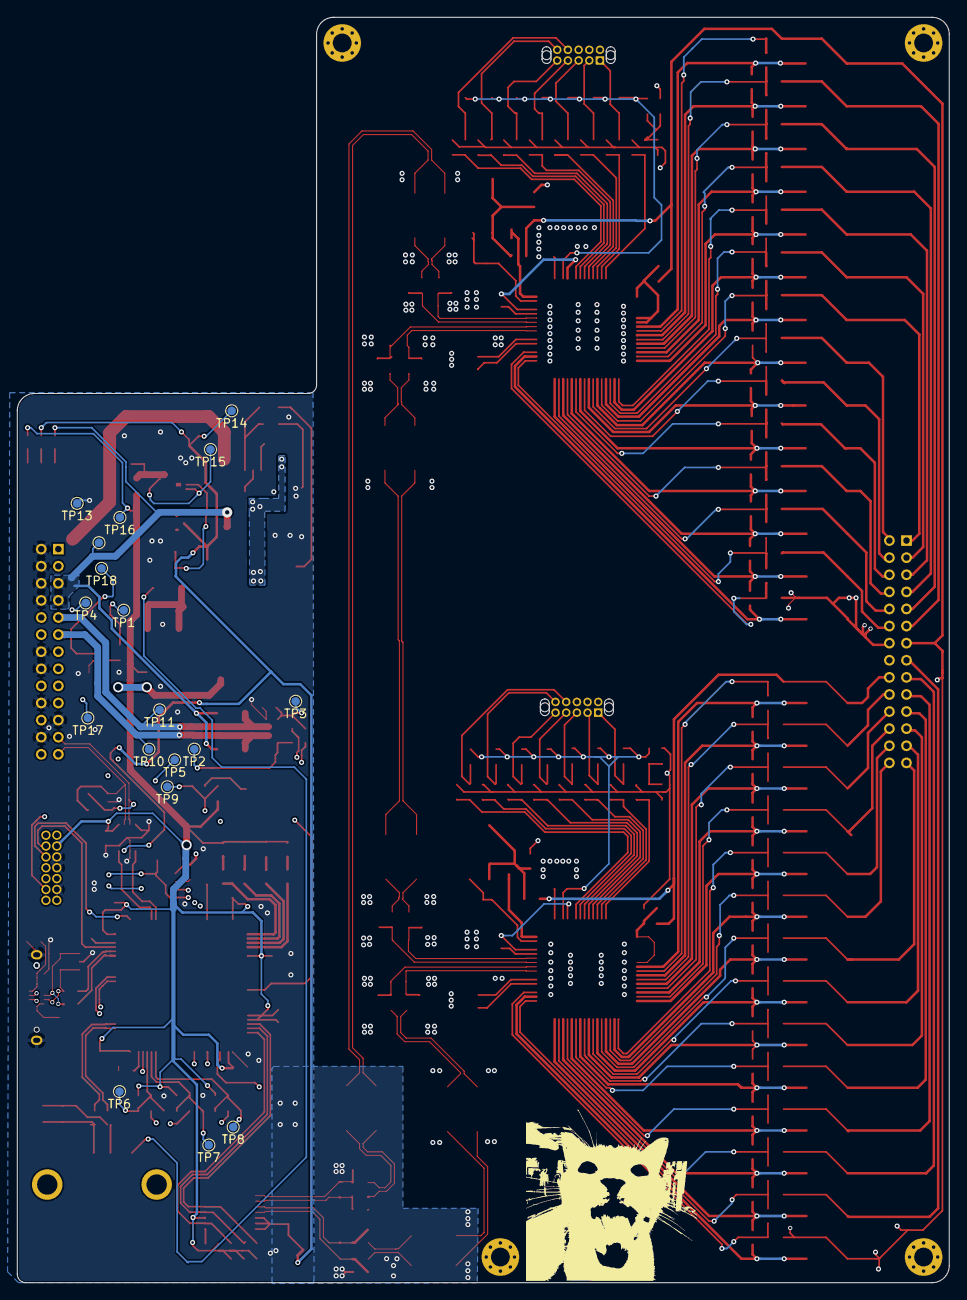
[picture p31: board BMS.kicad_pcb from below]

Board: 4 copper layers, 109.0 x 148.0 mm, 362 parts (18 on the bottom side), 235 nets.

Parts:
C1: 100n ceramiczny; C_0603_1608Metric_Pad1.08x0.95mm_HandSolder
C2, C51: 0.22uF; C_0603_1608Metric_Pad1.08x0.95mm_HandSolder
C3, C9, C52, C58: 0.1uF; C_0603_1608Metric_Pad1.08x0.95mm_HandSolder
C4, C53: 10nF; C_0603_1608Metric_Pad1.08x0.95mm_HandSolder
C5, C8, C42, C43, C44, C45, C46, C47, C48, C49, C50, C54, C57, C65, C66, C67, C68, C69, C70, C71, C72, C73, C74, C75, C76, C77, C78, C79, C134, C135, C136, C137, C138: 1uF; C_0603_1608Metric_Pad1.08x0.95mm_HandSolder
C6, C55: 4.7uF; C_0603_1608Metric_Pad1.08x0.95mm_HandSolder
C7, C56: 2.2uF; C_0603_1608Metric_Pad1.08x0.95mm_HandSolder
C10, C11, C14, C15, C59, C60, C63, C64, C113, C129, C132, C133: 220p; C_0603_1608Metric_Pad1.08x0.95mm_HandSolder
C12, C13, C61, C62, C130, C131, C142, C143, C144, C145, C146, C147: 2.2n; CAPC5728X280N
C16, C17, C18, C19, C20, C21, C22, C23, C24, C25, C26, C27, C28, C29, C30, C31, C32, C33, C34, C35, C36, C37, C38, C39, C40, C41, C80, C81, C82, C83, C84, C85, C86, C87, C88, C89, C90, C91, C92, C93, C94, C95, C96, C97, C98, C99, C100, C101, C102, C103, C104, C105: 0.47uF; C_0603_1608Metric_Pad1.08x0.95mm_HandSolder
C106, C110, C111, C112, C114, C115, C118: 0.1u; C_0603_1608Metric_Pad1.08x0.95mm_HandSolder
C107, C108: 0.22u; C_0603_1608Metric_Pad1.08x0.95mm_HandSolder
C109: 0.1uF 50V; C_0603_1608Metric_Pad1.08x0.95mm_HandSolder
C116, C117, C127: 100nF; C_0603_1608Metric_Pad1.08x0.95mm_HandSolder
C119: 10u; C_0805_2012Metric_Pad1.18x1.45mm_HandSolder
C120: 10uf; C_0805_2012Metric_Pad1.18x1.45mm_HandSolder
C121: 100n 280mOhm; C_0805_2012Metric_Pad1.18x1.45mm_HandSolder
C122, C123: 22u; C_0603_1608Metric_Pad1.08x0.95mm_HandSolder
C124: 22uF; CP_Elec_4x5.8
C125: 1uF; C_0603_1608Metric
C126, C128: 10uF; C_0603_1608Metric_Pad1.08x0.95mm_HandSolder
C139, C140: 2.2n; C_0603_1608Metric_Pad1.08x0.95mm_HandSolder
C141: 47n; C_0603_1608Metric_Pad1.08x0.95mm_HandSolder
D1, D8, D13: 60V/0.5/3A; D_SOD-123
D2, D3, D4, D5, D10, D14, D18: LED; LED_0603_1608Metric
D6, D7, D11, D12: ESDA5V3SC5; SOT-23-5
D9: 6V; D_SOD-123
D16: Diode TVS 12V; D_SOD-323F
D17: TVS diode 5V; D_SOD-323_HandSoldering
F2, F5: 1A; Fuse_0603_1608Metric_Pad1.05x0.95mm_HandSolder
F3: 3A; Fuse_0603_1608Metric_Pad1.05x0.95mm_HandSolder
F4: 5V/0.5A; Fuse_0805_2012Metric
F6: 2A; Fuse_0603_1608Metric_Pad1.05x0.95mm_HandSolder
H1, H2, H3, H4: MountingHole; MountingHole_2.2mm_M2_Pad_Via
IC1: STM32H742VIT6
IC2: TPS563200DDCR
J1: Conn_01x28; HARWIN_M80-5002842
J7: FTSH-107-01-L-D-K; FTSH-107-XX-YYY-D-K
J10, J16: Conn_01x10; HARWIN_G125-MV11005L1P
J11: USB4235-03-C_REVA; GCT_USB4235-03-C_REVA
J13: USB_A; USB1046GF0190LBA
J19: Conn_02x13_Counter_Clockwise; HARWIN_M80-5002642
JP1: Jumper_2_Small_Open; SolderJumper-2_P1.3mm_Open_Pad1.0x1.5mm
L1: 3.3u 20mOhm; CLF7045__
Q2, Q8: 100V/2W; SOT-223-3_TabPin2
Q5, Q7: DMT6018LDR-7; DMT6018LDR7
R1, R15, R101, R140: 100k; R_0603_1608Metric_Pad0.98x0.95mm_HandSolder
R2, R64, R155: 300; R_0603_1608Metric_Pad0.98x0.95mm_HandSolder
R3, R58: 100; R_0603_1608Metric
R4, R66: 30; R_0603_1608Metric_Pad0.98x0.95mm_HandSolder
R5, R8, R9, R10, R11, R12, R18, R50, R51, R52, R57, R67, R70, R74, R95, R96, R97, R98, R99, R106, R107, R108, R151, R152, R153, R154, R164: 1k; R_0603_1608Metric_Pad0.98x0.95mm_HandSolder
R6, R7, R13, R16, R60, R63, R65, R68, R69, R71, R72, R73: 49; R_0603_1608Metric_Pad0.98x0.95mm_HandSolder
R14, R17, R47, R48, R49, R53, R54, R55, R62, R100, R102, R103, R104, R105, R109, R110, R111, R141, R142, R146, R150, R157, R159: 10k; R_0603_1608Metric_Pad0.98x0.95mm_HandSolder
R19, R20, R21, R22, R23, R24, R25, R26, R27, R28, R29, R30, R31, R32, R112, R113, R114, R115, R116, R117, R118, R119, R120, R121, R122, R123, R124, R125, R160, R161: 100; R_0603_1608Metric_Pad0.98x0.95mm_HandSolder
R33, R34, R35, R36, R37, R38, R39, R40, R41, R42, R43, R44, R45, R46, R126, R127, R128, R129, R130, R131, R132, R133, R134, R135, R136, R137, R138, R139: 10; RESC6331X80N
R56, R59: 10k; R_0603_1608Metric
R61: 15.8k; R_0603_1608Metric_Pad0.98x0.95mm_HandSolder
R75, R76: 5.1K; R_0603_1608Metric
R145, R149, R156, R158: 500; R_0603_1608Metric_Pad0.98x0.95mm_HandSolder
R162: 130; R_0603_1608Metric_Pad0.98x0.95mm_HandSolder
R163: 4.7k; R_0603_1608Metric_Pad0.98x0.95mm_HandSolder
R165: 56.2k 50mW; R_0603_1608Metric_Pad0.98x0.95mm_HandSolder
R166: 10k 50mW; R_0603_1608Metric_Pad0.98x0.95mm_HandSolder
R173, R174, R175, R176: 33; R_0603_1608Metric
SW1: SW_Push; 1478732
TH1, TH13: 10k b= 3000; R_0603_1608Metric_Pad0.98x0.95mm_HandSolder
TP1, TP2, TP3, TP4, TP5, TP6, TP7, TP8, TP9, TP10, TP11, TP12, TP13, TP14, TP15, TP16, TP17, TP18: TestPoint_Small; TestPoint_Pad_D1.0mm
U1, U2: BQ79614PAPRQ1
U3: PBQ79600PWQ1; BQ79600-Q1
U4: MCP2542FD-E/MF; DFN-8-1EP_3x3mm_P0.65mm_EP1.55x2.4mm
U5: PTPSM863253RDXR; RDX0007A-MFG_NOVIA

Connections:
12V_IN: C134.1, C135.1, D16.2 (A2), F3.1, J19.1
+3.3V: C1.2, C65.2, C66.1, C67.2, C68.1, C69.2, C70.1, C106.1, C116.2, C141.2, D2.2 (A), D3.2 (A), D4.2 (A), D5.2 (A), D14.2 (A), F5.2, IC1.6 (VBAT), IC1.20 (VREF+), IC1.21 (VDDA), IC1.27 (VDD_2), IC1.50 (VDD_3), IC1.75 (VDD_4), IC1.100 (VDD_5), J7.3, R140.2, R141.2, R142.2, R146.1, R150.1, R157.1, R159.1, TP16.1, U3.3 (VIO), U4.5 (VIO)
+5V: C108.1, C109.1, C117.1, C126.1, C127.1, D10.2 (A), D17.2 (A2), F2.2, R61.1, TP14.1, U3.14 (CVDD), U3.15 (BAT), U3.16 (INH), U4.3 (VDD), U5.1 (VIN)
+5V_external: F6.2, J19.9, J19.10, TP17.1
+12V: C119.1, C120.1, D1.1 (K), D13.1 (K), D18.2 (A), F3.2, IC2.3 (VIN), IC2.5 (EN), J19.3, J19.4, TP12.1
/12V_Enable: IC1.29 (PA5), R161.1, TP1.1
/Button1: C110.2, IC1.47 (PB11), R145.2, R146.2, TP9.1
/Button2: C111.2, IC1.46 (PB10), R149.2, R150.2, TP6.1
/Button3: C112.2, IC1.45 (PE15), R156.2, R157.2, TP7.1
/Button4: C114.2, IC1.44 (PE14), R158.2, R159.2, TP8.1
/CAN_RX: IC1.81 (PD0), U4.4 (RXD)
/CAN_TX: IC1.82 (PD1), U4.1 (TXD)
/Connectivity/5V_fused_minus: J19.7, J19.8, Q7.5 (D1), TP18.1
/Connectivity/+5V_curr_sense: C115.2, D6.1 (K), J19.2
/Connectivity/B2_IN: J19.26, R149.1
/Connectivity/B3_IN: J19.24, R156.1
/Connectivity/B4_IN: J19.22, R158.1
/Connectivity/Curr_sense_out: J19.18, JP1.1 (A), R160.1, TP4.1
/Connectivity/D1: D1.2 (A), J19.6, Q5.5 (D1), TP10.1
/Connectivity/D2: D13.2 (A), J19.5, Q5.6 (D2), TP11.1
/Connectivity/EX_CANFD+: D7.3 (K), D7.5 (K), J19.12, U4.7 (CANH)
/Connectivity/EX_CANFD-: D7.1 (K), D7.4 (K), J19.13, U4.6 (CANL)
/Connectivity/G1: Q5.1 (G1), R3.2, R56.2, TP2.1
/Connectivity/G2: Q5.4 (G2), R58.2, R59.2, TP3.1
/Connectivity/G3: Q7.1 (G1), R161.2, R163.2
/Connectivity/USB1_DN: D12.1 (K), D12.5 (K), J11.A7 (DN1), J11.B7 (DN2), R176.2
/Connectivity/USB1_DP: D12.3 (K), D12.4 (K), J11.A6 (DP1), J11.B6 (DP2), R175.2
/Curr_sense: C118.2, D6.5 (K), IC1.32 (PC4), JP1.2 (B), R160.2
/Curr_sense2: D6.3 (K), IC1.35 (PB1), J19.19, TP5.1
/ERROR: IC1.1 (PE2), R154.1
/LED1: IC1.2 (PE3), R153.1
/LED2: IC1.3 (PE4), R152.1
/LED3: IC1.4 (PE5), R151.1
/Mesurements_LTC1/Bat_pin: C4.2, R4.2, U1.1 (BAT), U1.6 (CB14), U1.7 (VC14)
/Mesurements_LTC1/CB0: C41.1, R46.2, U1.34 (CB0)
/Mesurements_LTC1/CB1: C40.1, C41.2, R45.2, U1.32 (CB1)
/Mesurements_LTC1/CB2: C39.1, C40.2, R44.2, U1.30 (CB2)
/Mesurements_LTC1/CB3: C38.1, C39.2, R43.2, U1.28 (CB3)
/Mesurements_LTC1/CB4: C37.1, C38.2, R42.2, U1.26 (CB4)
/Mesurements_LTC1/CB5: C36.1, C37.2, R41.2, U1.24 (CB5)
/Mesurements_LTC1/CB6: C35.1, C36.2, R40.2, U1.22 (CB6)
/Mesurements_LTC1/CB7: C34.1, C35.2, R39.2, U1.20 (CB7)
/Mesurements_LTC1/CB8: C33.1, C34.2, R38.2, U1.18 (CB8)
/Mesurements_LTC1/CB9: C32.1, C33.2, R37.2, U1.16 (CB9)
/Mesurements_LTC1/CB10: C31.1, C32.2, R36.2, U1.14 (CB10)
/Mesurements_LTC1/CB11: C30.1, C31.2, R35.2, U1.12 (CB11)
/Mesurements_LTC1/CB12: C29.1, C30.2, R34.2, U1.10 (CB12)
/Mesurements_LTC1/CB13: C29.2, R33.2, U1.8 (CB13)
/Mesurements_LTC1/COMHN: C60.2, R67.2, R71.1, U1.42 (COMHN)
/Mesurements_LTC1/COMHP: C59.2, R67.1, R68.1, U1.43 (COMHP)
/Mesurements_LTC1/COMLN: C133.2, R65.2, R70.2, U1.41 (COMLN)
/Mesurements_LTC1/COMLP: C132.2, R69.2, R70.1, U1.40 (COMLP)
/Mesurements_LTC1/Temperature_LTC_1/T1: C42.1, R8.1, U1.61 (GPIO1)
/Mesurements_LTC1/Temperature_LTC_1/T2: C45.1, R11.1, U1.60 (GPIO2)
/Mesurements_LTC1/Temperature_LTC_1/T3: C46.1, R12.1, U1.59 (GPIO3)
/Mesurements_LTC1/Temperature_LTC_1/T4: C43.1, R9.1, U1.58 (GPIO4)
/Mesurements_LTC1/Temperature_LTC_1/T5: C44.1, R10.1, U1.57 (GPIO5)
/Mesurements_LTC1/Temperature_LTC_1/T6: C48.1, R50.1, U1.56 (GPIO6)
/Mesurements_LTC1/Temperature_LTC_1/T7: C49.1, R51.1, U1.55 (GPIO7)
/Mesurements_LTC1/Temperature_LTC_1/T8: C50.1, R52.1, U1.54 (GPIO8)
/Mesurements_LTC1/Temperature_LTC_1/TSREF: C47.1, R14.1, R17.2, R47.2, R48.2, R49.2, R53.2, R54.2, R55.2, U1.51 (TSREF)
/Mesurements_LTC1/Temperature_LTC_1/Thermistor2: J16.1, R11.2, R48.1
/Mesurements_LTC1/Temperature_LTC_1/Thermistor3: J16.2, R12.2, R49.1
/Mesurements_LTC1/Temperature_LTC_1/Thermistor4: J16.3, R9.2, R17.1
/Mesurements_LTC1/Temperature_LTC_1/Thermistor5: J16.4, R10.2, R47.1
/Mesurements_LTC1/Temperature_LTC_1/Thermistor6: J16.5, R50.2, R53.1
/Mesurements_LTC1/Temperature_LTC_1/Thermistor7: J16.10, R51.2, R54.1
/Mesurements_LTC1/Temperature_LTC_1/Thermistor8: J16.9, R52.2, R55.1
/Mesurements_LTC1/VC0: C28.1, R19.2, U1.35 (VC0)
/Mesurements_LTC1/VC1: C27.1, C28.2, R32.2, U1.33 (VC1)
/Mesurements_LTC1/VC2: C26.1, C27.2, R31.2, U1.31 (VC2)
/Mesurements_LTC1/VC3: C25.1, C26.2, R30.2, U1.29 (VC3)
/Mesurements_LTC1/VC4: C24.1, C25.2, R29.2, U1.27 (VC4)
/Mesurements_LTC1/VC5: C23.1, C24.2, R28.2, U1.25 (VC5)
/Mesurements_LTC1/VC6: C22.1, C23.2, R27.2, U1.23 (VC6)
/Mesurements_LTC1/VC7: C21.1, C22.2, R26.2, U1.21 (VC7)
/Mesurements_LTC1/VC8: C20.1, C21.2, R25.2, U1.19 (VC8)
/Mesurements_LTC1/VC9: C19.1, C20.2, R24.2, U1.17 (VC9)
/Mesurements_LTC1/VC10: C18.1, C19.2, R23.2, U1.15 (VC10)
/Mesurements_LTC1/VC11: C17.1, C18.2, R22.2, U1.13 (VC11)
/Mesurements_LTC1/VC12: C16.1, C17.2, R21.2, U1.11 (VC12)
/Mesurements_LTC1/VC13: C16.2, R20.2, U1.9 (VC13)
/Mesurements_LTC1/to_rx: C6.2, U1.45 (CVDD), U1.52 (RX)
/Mesurements_LTC2/CB0: C105.1, R139.2, U2.34 (CB0)
/Mesurements_LTC2/CB1: C104.1, C105.2, R138.2, U2.32 (CB1)
/Mesurements_LTC2/CB2: C103.1, C104.2, R137.2, U2.30 (CB2)
/Mesurements_LTC2/CB3: C102.1, C103.2, R136.2, U2.28 (CB3)
/Mesurements_LTC2/CB4: C101.1, C102.2, R135.2, U2.26 (CB4)
/Mesurements_LTC2/CB5: C100.1, C101.2, R134.2, U2.24 (CB5)
/Mesurements_LTC2/CB6: C99.1, C100.2, R133.2, U2.22 (CB6)
/Mesurements_LTC2/CB7: C98.1, C99.2, R132.2, U2.20 (CB7)
/Mesurements_LTC2/CB8: C97.1, C98.2, R131.2, U2.18 (CB8)
/Mesurements_LTC2/CB9: C96.1, C97.2, R130.2, U2.16 (CB9)
/Mesurements_LTC2/CB10: C95.1, C96.2, R129.2, U2.14 (CB10)
/Mesurements_LTC2/CB11: C94.1, C95.2, R128.2, U2.12 (CB11)
/Mesurements_LTC2/CB12: C93.1, C94.2, R127.2, U2.10 (CB12)
/Mesurements_LTC2/CB13: C93.2, R126.2, U2.8 (CB13)
/Mesurements_LTC2/COMHN: C129.2, R57.2, R63.1, U2.42 (COMHN)
/Mesurements_LTC2/COMHP: C113.2, R57.1, R60.1, U2.43 (COMHP)
/Mesurements_LTC2/COMLN: C15.2, R13.2, R18.2, U2.41 (COMLN)
/Mesurements_LTC2/COMLP: C14.2, R16.2, R18.1, U2.40 (COMLP)
/Mesurements_LTC2/Temperature_LTC_2/T1: C72.1, R95.1, U2.61 (GPIO1)
/Mesurements_LTC2/Temperature_LTC_2/T2: C75.1, R98.1, U2.60 (GPIO2)
/Mesurements_LTC2/Temperature_LTC_2/T3: C76.1, R99.1, U2.59 (GPIO3)
/Mesurements_LTC2/Temperature_LTC_2/T4: C73.1, R96.1, U2.58 (GPIO4)
/Mesurements_LTC2/Temperature_LTC_2/T5: C74.1, R97.1, U2.57 (GPIO5)
/Mesurements_LTC2/Temperature_LTC_2/T6: C77.1, R106.1, U2.56 (GPIO6)
/Mesurements_LTC2/Temperature_LTC_2/T7: C78.1, R107.1, U2.55 (GPIO7)
/Mesurements_LTC2/Temperature_LTC_2/T8: C79.1, R108.1, U2.54 (GPIO8)
/Mesurements_LTC2/Temperature_LTC_2/TSREF: C71.1, R100.1, R102.2, R103.2, R104.2, R105.2, R109.2, R110.2, R111.2, U2.51 (TSREF)
/Mesurements_LTC2/Temperature_LTC_2/Thermistor1: R95.2, R100.2, R101.1, TH13.1
/Mesurements_LTC2/Temperature_LTC_2/Thermistor2: J10.1, R98.2, R104.1
/Mesurements_LTC2/Temperature_LTC_2/Thermistor3: J10.2, R99.2, R105.1
/Mesurements_LTC2/Temperature_LTC_2/Thermistor4: J10.3, R96.2, R102.1
/Mesurements_LTC2/Temperature_LTC_2/Thermistor5: J10.4, R97.2, R103.1
/Mesurements_LTC2/Temperature_LTC_2/Thermistor6: J10.5, R106.2, R109.1
/Mesurements_LTC2/Temperature_LTC_2/Thermistor7: J10.10, R107.2, R110.1
/Mesurements_LTC2/Temperature_LTC_2/Thermistor8: J10.9, R108.2, R111.1
/Mesurements_LTC2/VC0: C92.1, R112.2, U2.35 (VC0)
/Mesurements_LTC2/VC1: C91.1, C92.2, R125.2, U2.33 (VC1)
/Mesurements_LTC2/VC2: C90.1, C91.2, R124.2, U2.31 (VC2)
/Mesurements_LTC2/VC3: C89.1, C90.2, R123.2, U2.29 (VC3)
/Mesurements_LTC2/VC4: C88.1, C89.2, R122.2, U2.27 (VC4)
/Mesurements_LTC2/VC5: C87.1, C88.2, R121.2, U2.25 (VC5)
/Mesurements_LTC2/VC6: C86.1, C87.2, R120.2, U2.23 (VC6)
/Mesurements_LTC2/VC7: C85.1, C86.2, R119.2, U2.21 (VC7)
/Mesurements_LTC2/VC8: C84.1, C85.2, R118.2, U2.19 (VC8)
/Mesurements_LTC2/VC9: C83.1, C84.2, R117.2, U2.17 (VC9)
/Mesurements_LTC2/VC10: C82.1, C83.2, R116.2, U2.15 (VC10)
/Mesurements_LTC2/VC11: C81.1, C82.2, R115.2, U2.13 (VC11)
/Mesurements_LTC2/VC12: C80.1, C81.2, R114.2, U2.11 (VC12)
/Mesurements_LTC2/VC13: C80.2, R113.2, U2.9 (VC13)
/Mesurements_LTC2/to_rx: C55.2, U2.45 (CVDD), U2.52 (RX)
/NFAULT: IC1.24 (PA2), R140.1, U3.2 (NFAULT)
/NRST: IC1.14 (NRST), J7.12
/Power/5V/5V_unfused: C122.1, C123.1, C136.1, F2.1, F4.2, F6.1, L1.2, R165.2
/Power/5V/F_U5V: C124.1, C125.2, D8.1 (K), D9.1 (K), F4.1
/RX_1: IC1.23 (PA1), R142.1, U3.4 (MOSI/RX)
/SIGNAL_PRECHARGE: IC1.65 (PC8), R58.1
/SIGNAL_RELAY: IC1.64 (PC7), R3.1
/STM Comunication Interface /COMHN: C11.2, R5.2, R7.1, U3.12 (COMHN)
/STM Comunication Interface /COMHP: C10.2, R5.1, R6.1, U3.13 (COMHP)
/STM Comunication Interface /COMLN: C64.2, R72.2, R74.2, U3.11 (COMLN)
/STM Comunication Interface /COMLP: C63.2, R73.2, R74.1, U3.10 (COMLP)
/SWCLK: IC1.76 (PA14), J7.6
/SWDIO: IC1.72 (PA13), J7.4
/TX_1: IC1.22 (PA0), R141.1, U3.5 (MISO/TX)
/USB2+: IC1.54 (PB15), R173.1
/USB2-: IC1.53 (PB14), R174.1
/USB+: IC1.71 (PA12), R175.1
/USB-: IC1.70 (PA11), R176.1
/galvanic_isulation_0/S1+: C61.2, R68.2
/galvanic_isulation_0/S1-: C62.2, R71.2
/galvanic_isulation_0/S2+: C61.1, C147.2
/galvanic_isulation_0/S2-: C62.1, C146.2
/galvanic_isulation_0/S3+: C147.1, R73.1
/galvanic_isulation_0/S3-: C146.1, R72.1
/galvanic_isulation_1/S1+: C130.2, R60.2
/galvanic_isulation_1/S1-: C131.2, R63.2
/galvanic_isulation_1/S2+: C130.1, C142.2
/galvanic_isulation_1/S2-: C131.1, C143.2
/galvanic_isulation_1/S3+: C142.1, R69.1
/galvanic_isulation_1/S3-: C143.1, R65.1
/galvanic_isulation_2/S1+: C12.2, R6.2
/galvanic_isulation_2/S1-: C13.2, R7.2
/galvanic_isulation_2/S2+: C12.1, C145.2
/galvanic_isulation_2/S2-: C13.1, C144.2
/galvanic_isulation_2/S3+: C145.1, R16.1
/galvanic_isulation_2/S3-: C144.1, R13.1
Batt_Coupling: C14.1, C15.1, C51.1, C52.1, C53.1, C54.1, C55.1, C56.1, C57.1, C58.1, C71.2, C72.2, C73.2, C74.2, C75.2, C76.2, C77.2, C78.2, C79.2, C113.1, C129.1, J1.14, J10.6, J10.7, J10.8, R2.1, R4.1, R20.1, R33.1, R101.2, R112.1, R139.1, TH13.2, U2.36 (REFHM), U2.39 (AVSS), U2.46 (CVSS), U2.50 (DVSS), U2.65 (PAD)
CELL14: J1.15, R125.1, R138.1
CELL15: J1.16, R124.1, R137.1
CELL16: J1.17, R123.1, R136.1
CELL17: J1.18, R122.1, R135.1
CELL18: J1.19, R121.1, R134.1
CELL19: J1.20, R120.1, R133.1
CELL20: J1.21, R119.1, R132.1
CELL21: J1.22, R118.1, R131.1
CELL22: J1.23, R117.1, R130.1
CELL23: J1.24, R116.1, R129.1
CELL24: J1.25, R115.1, R128.1
CELL25: J1.26, R114.1, R127.1
CELL26: J1.27, R64.1, R66.1, R113.1, R126.1
GND: C1.1, C10.1, C11.1, C63.1, C64.1, C65.1, C66.2, C67.1, C68.2, C69.1, C70.2, C106.2, C107.1, C108.2, C109.2, C110.1, C111.1, C112.1, C114.1, C115.1, C116.1, C117.2, C118.1, C119.2, C120.2, C122.2, C123.2, C124.2, C125.1, C126.2, C127.2, C128.2, C134.2, C135.2, C136.2, C137.2, C138.2, C139.1, C141.1, D6.2 (A), D6.4 (K), D7.2 (A), D9.2 (A), D11.2 (A), D12.2 (A), D16.1 (A1), D17.1 (A1), IC1.19 (VSSA), IC1.26 (VSS_2), IC1.49 (VSS_3), IC1.74 (VSS_4), IC1.99 (VSS_5), IC2.1 (GND), J7.5, J7.7, J7.11, J11.A1 (GND_A), J11.A12 (GND_A), J11.B1 (GND_B), J11.B12 (GND_B), J11.SH1 (SHIELD), J11.SH2 (SHIELD), J13.4 (GND), J19.11, J19.14, J19.15, J19.16, J19.17, J19.20, J19.21, J19.23, J19.25, Q5.2 (S1), Q5.3 (S2), Q7.2 (S1), R1.1, R56.1, R59.1, R62.2, R75.1, R76.2, R155.1, R162.1, R163.1, R164.1, R166.1, SW1.2, TP13.1, U3.6 (SCLK), U3.7 (nCS), U3.8 (nUART/SPI(SPI_RDY)), U3.9 (GND), U4.2 (VSS), U4.8 (~STBY), U4.9 (VSS), U5.4 (PGND)
unnamed: D2.1 (K), R151.2
unnamed: D3.1 (K), R152.2
unnamed: D4.1 (K), R153.2
unnamed: D5.1 (K), R154.2
unnamed: D10.1 (K), R155.2
unnamed: D14.1 (K), R162.2
unnamed: D18.1 (K), R164.2
unnamed: IC1.94 (BOOT0), R1.2
unnamed: C139.2, IC1.48 (VCAP_1)
unnamed: C140.2, IC1.73 (VCAP_2)
unnamed: C121.1, IC2.2 (SW), L1.1
unnamed: C121.2, IC2.6 (VBST)
unnamed: IC2.4 (VFB), R165.1, R166.2
unnamed: J1.2, R32.1, R45.1
unnamed: J1.3, R31.1, R44.1
unnamed: J1.4, R30.1, R43.1
unnamed: J1.5, R29.1, R42.1
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

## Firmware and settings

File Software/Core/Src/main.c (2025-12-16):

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
/* Includes ------------------------------------------------------------------*/
#include "main.h"
#include "usb_device.h"

/* USER CODE BEGIN Includes */
#include "bq79600.h"
#include "bq79600_def.h"
#include "bq79616_def.h"
#include "SEGGER_RTT.h"
#include "usbd_cdc_if.h"
#include "stm32h7xx_hal_gpio.h"
#include <string.h>
#include <stdio.h>
//#include "Structs.h"
/* USER CODE END Includes */

/* USER CODE BEGIN PTD */
#define MSGQUEUE_OBJECTS 16
/* USER CODE END PTD */

ADC_HandleTypeDef hadc1;
extern USBD_HandleTypeDef hUsbDeviceFS;
FDCAN_HandleTypeDef hfdcan1;
TIM_HandleTypeDef htim1;
TIM_HandleTypeDef htim2;

UART_HandleTypeDef huart4;
DMA_HandleTypeDef hdma_uart4_tx;
DMA_HandleTypeDef hdma_uart4_rx;

PCD_HandleTypeDef hpcd_USB_OTG_HS;

/* USER CODE BEGIN PV */
int Safety_Error;
int Battery_status; // 0 = standby, 1= charging , 2=discharging , 3 =  Error
int ballancing;
int data_in;
int current_raw;
BQ_Data BqMeasurements[2];

typedef struct {
  char Buf[64];
  uint32_t Timestamp;
} Message;
Message msg;

//usb receive variables
uint8_t usbRxBuf[128];
uint16_t usbRxBufLen;
uint8_t usbRxFlag = 0 ;

// digital lowpass filter variable
float alpha = 0.5f;    // adjust as needed (0.05–0.2 is common)

int current_raw = 31000;   // your ADC reading each loop
float current_filtered = 31000;  // filtered output
float current = 0 ;
////

char message[128];
char buffer_usb1[] = "BMS TEST /n";
char buffer_usb2[] = "PORT COMM TEST /n";
char buffer_usb3[] = "USB FS TEST /n";
char bq_message[32] = {0};
char message_buffer[32];

volatile uint8_t CDC_TransmitReady = 1;





/* USER CODE END PV */

void SystemClock_Config(void);
static void MPU_Config(void);
static void MX_GPIO_Init(void);
static void MX_DMA_Init(void);
void MX_UART4_Init(int boudrate);
static void MX_TIM1_Init(void);
static void MX_TIM2_Init(void);
static void MX_ADC1_Init(void);
static void MX_FDCAN1_Init(void);
static void MX_USB_OTG_HS_PCD_Init(void);
/* USER CODE BEGIN PFP */
float convert_adc_to_current(float data);
void BQ_COMM(bq79600_t *bms_instance);
void Usb_COMM();
//#define bms_fault(state) HAL_GPIO_WritePin(GPIOA, GPIO_PIN_2, (state) ? GPIO_PIN_RESET : GPIO_PIN_SET)
//#define bms_run() HAL_GPIO_TogglePin(GPIOC, GPIO_PIN_13)
/* USER CODE END PFP */

/* USER CODE BEGIN 0 */



/*
void HAL_UARTEx_RxEventCallback(UART_HandleTypeDef *huart, uint16_t size) {
  static bq79600_t *instance = NULL;
  instance = open_bq79600_instance(0);
  if (instance == NULL) instance = open_bq79600_instance(0);
  instance->rx_len = size;
  bq79600_rx_callback(instance);
  HAL_UARTEx_ReceiveToIdle_IT(&huart4, instance->rx_buf, sizeof(instance->rx_buf));
} */
void USB_RXCallback(uint8_t* Buf, uint32_t *Len)
{
	memcpy(usbRxBuf, Buf, *Len);
	usbRxBufLen = *Len;
	usbRxFlag = 1;
}
/*
int voltage_to_temperature(float voltage) // formula based of fitted logarytmic function fitted in curve fitting
                                          // toolbox in matlab
{
	if(voltage > 3500)
		return 0;
	else
		return -50.2*log(voltage)+ 416;
}
int voltage_to_temperature2(float voltage) // formula based of fitted logarytmic function fitted in curve fitting
                                          // toolbox in matlab this one if for 0603 ntc thermistor that has a different B value
{
	if(voltage > 3500)
		return 0;
	else
		return 154/(1 + exp(0.0012*(voltage-910)));
} */

UART_HandleTypeDef huart4;
DMA_HandleTypeDef hdma_usart4_tx;
DMA_HandleTypeDef hdma_usart4_rx;


#define bms_run() HAL_GPIO_TogglePin(GPIOE, GPIO_PIN_5) ;
/* USER CODE END 0 */

/**
  * @brief  The application entry point.
  * @retval int
  */
int main(void)
{

  /* MPU Configuration--------------------------------------------------------*/
  MPU_Config();

  /* MCU Configuration--------------------------------------------------------*/

  /* Reset of all peripherals, Initializes the Flash interface and the Systick. */
  HAL_Init();

  /* USER CODE BEGIN Init */
  //SEGGER_RTT_Init();
  /* USER CODE END Init */

  /* Configure the system clock */
  SystemClock_Config();

  /* Initialize all configured peripherals */
  MX_GPIO_Init();
  MX_DMA_Init();
  MX_UART4_Init(1000000);
  MX_TIM1_Init();
  MX_TIM2_Init();
  MX_ADC1_Init();
  MX_FDCAN1_Init();
  MX_USB_OTG_HS_PCD_Init();
  MX_USB_DEVICE_Init();
  /* USER CODE BEGIN 2 */
  HAL_TIM_Base_Start(&htim2);
  HAL_TIM_Base_Start(&htim1);
  HAL_GPIO_WritePin(GPIOC, GPIO_PIN_7, GPIO_PIN_SET);
  /* USER CODE END 2 */

  /* Infinite loop */
  /* USER CODE BEGIN WHILE */
  HAL_ADC_Start(&hadc1);
  Safety_Error = 0 ;
   bq79600_t *bms_instance = open_bq79600_instance(0);
   BQ_INNIT(bms_instance);




   while(1)
   {
 	  BQ_COMM(bms_instance);
 	 if (HAL_ADC_PollForConversion(&hadc1, 10) == HAL_OK)
 	 {
 		        current_raw = HAL_ADC_GetValue(&hadc1);
 	 			HAL_ADC_Start(&hadc1);
 	 			current_filtered = current_filtered +
 	 			                       alpha * (current_raw - current_filtered);
 	 }
 	 current = convert_adc_to_current(current_filtered);
 	  if (hUsbDeviceFS.dev_state == USBD_STATE_CONFIGURED)
 	  Usb_COMM();
 	  Safety();
 	  Led();
 	  HAL_Delay(250);
   }
    /* USER CODE END WHILE */




}

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
/* USER CODE BEGIN 4 */
void BQ_INNIT(bq79600_t *bms_instance)
{
	//bq79600_t *bms_instance = open_bq79600_instance(0);

	bms_instance->mode = BQ_UART;
	bms_instance->state = BQ_SHUTDOWN;
	bms_instance->rx_port = GPIOA;
	bms_instance->tx_port = GPIOA;
	bms_instance->rx_pin = 1;
	bms_instance->tx_pin = 0;

	// wake up ping using slowed uart communication
	HAL_UART_DeInit(&huart4);
	MX_UART4_Init(3250);
	HAL_Delay(10);
	uint8_t zero=0x00;
	HAL_UART_Transmit(&huart4,&zero,1,100);
	HAL_Delay(13);
	HAL_UART_Transmit(&huart4,&zero,1,100);
	HAL_Delay(50);
	HAL_UART_DeInit(&huart4);
	MX_UART4_Init(1000000);
	 if( HAL_UARTEx_ReceiveToIdle_IT(&huart4, bms_instance->rx_buf, sizeof(bms_instance->rx_buf)) == HAL_ERROR)
	 {
		 while (1);
	 }
	  HAL_Delay(10);

	   if( HAL_UART_Transmit_IT(&huart4, bms_instance->tx_buf, bms_instance->tx_len) == HAL_BUSY)
	   {
		   while (1);
	   }
	initalize_communication(bms_instance,&huart4,N_DEVICES,N_CELLS_PER_DEVICE);
	uint8_t buf = 0xFF;
	bq79600_construct_command(bms_instance, STACK_WRITE, 0, FAULT_MSK1, 1 , NULL);

	//uint8_t buf = 0x3;
	// uint32_t start_cbcells = CB_CELL1_CTRL - N_CELLS_PER_DEVICE  + 1;


	HAL_Delay(15);
}
void BQ_COMM(bq79600_t *bms_instance)
{
	        uint8_t buf;



 	         bq79600_construct_command(bms_instance, STACK_READ, 0, DIETEMP1_HI, 2, NULL);
 	         bq79600_tx(bms_instance);
 	         bq79600_bsp_ready(bms_instance);
 	         for (int i = 0; i < N_DEVICES - 1; i++)
 	         {
 	           modules[i].dietemp = raw_to_float(&bms_instance->rx_buf[4 + i * 8]) * 0.025;
 	         }


 	         uint32_t start_vcells = VCELL1_HI - N_CELLS_PER_DEVICE * 2 + 2;
 	         bq79600_construct_command(bms_instance, STACK_READ, 0, start_vcells, N_CELLS_PER_DEVICE * 2, NULL);
 	         bq79600_tx(bms_instance);
 	         bq79600_bsp_ready(bms_instance);
 	         for (int i = 0; i <N_DEVICES - 1; i++)
 	         {
 	           for (int j = 0; j < N_CELLS_PER_DEVICE; j++)
 	           {
 	             modules[i].vcells[j] =
 	                 raw_to_float(&bms_instance->rx_buf[4 + i * (N_CELLS_PER_DEVICE * 2 + 6) + 2 * j]) * 0.19073;
 	           }
 	         } // bq2 temp 2 works fine

 	       // osDelay(5);

 	         uint32_t start_temp = GPIO1_HI  ;
 	         bq79600_construct_command(bms_instance, STACK_READ, 0, start_temp, N_TEMPS_PER_DEVICE * 2, NULL);
 	         bq79600_tx(bms_instance);
 	         bq79600_bsp_ready(bms_instance);

 	         for (int i = 0; i < N_DEVICES - 1; i++)
 	         {
 	           for (int j = 0; j < N_TEMPS_PER_DEVICE; j++)
 	           {
 	        	   if(j==0)
 	        	   {
 	        		 modules[i].temperature[j] =voltage_to_temperature2(
 	        		   	                 raw_to_float(&bms_instance->rx_buf[4 + i * (N_TEMPS_PER_DEVICE * 2 + 6) + 2 * j ] )  * 0.15259);
 	        	   }
 	        	   else
 	        	   {
 	             modules[i].temperature[j] =voltage_to_temperature(
 	                 raw_to_float(&bms_instance->rx_buf[4 + i * (N_TEMPS_PER_DEVICE * 2 + 6) + 2 * j ] )  * 0.15259);
 	        	   }
 	           }
 	         }


 	       // HAL_Delay(10);

 	         uint32_t start_temp_ref = TSREF_HI ;
 	         bq79600_construct_command(bms_instance, STACK_READ, 0, start_temp_ref, 2, NULL);
 	         bq79600_tx(bms_instance);
 	         bq79600_bsp_ready(bms_instance);
 	         for (int i = 0; i < N_DEVICES - 1; i++)
 	             modules[i].t_ref =
 	                 raw_to_float(&bms_instance->rx_buf[4 + i * 8]) * 0.16954;






 	         for (int i = 0; i < N_DEVICES - 1; i++) modules[i].timestamp = HAL_GetTick() ;


 	         bq79600_construct_command(bms_instance, STACK_READ, 0, BAL_STAT, 1, NULL); // BAL_STAT READ.
 	         bq79600_tx(bms_instance);
 	         bq79600_bsp_ready(bms_instance);
 	         for (int i = 0; i < N_DEVICES - 1; i++)
 	         modules[i].BAL_STAT_RAW = bms_instance->rx_buf[4 + i * 7];

 	         bq79600_construct_command(bms_instance, STACK_READ, 0, CB_COMPLETE1, 1, NULL); // BAL_STAT READ.
 	         bq79600_tx(bms_instance);
 	         bq79600_bsp_ready(bms_instance);
 	         for (int i = 0; i < N_DEVICES - 1; i++)
 	         modules[i].CB_COMPLETE1_RAW = bms_instance->rx_buf[4 + i * 7];

 	         bq79600_construct_command(bms_instance, STACK_READ, 0, CB_COMPLETE2, 1, NULL); // BAL_STAT READ.
 	         bq79600_tx(bms_instance);
 	         bq79600_bsp_ready(bms_instance);
 	         for (int i = 0; i < N_DEVICES - 1; i++)
 	         modules[i].CB_COMPLETE2_RAW = bms_instance->rx_buf[4 + i * 7];



 	         bq79600_construct_command(bms_instance, STACK_READ, 0, DEV_STAT, 1, NULL); // DEV_STAT READ.
 	         bq79600_tx(bms_instance);
 	         bq79600_bsp_ready(bms_instance);
 	         for (int i = 0; i < N_DEVICES - 1; i++)
 	         modules[i].DEV_STAT_RAW = bms_instance->rx_buf[4 + i * 7];



 	         bq79600_construct_command(bms_instance, STACK_READ, 0,  FAULT_UV1, 1, NULL); // DEV_STAT READ.
 	         bq79600_tx(bms_instance);
 	         bq79600_bsp_ready(bms_instance);
 	         for (int i = 0; i < N_DEVICES - 1; i++)
 	         modules[i].UV_RAW_1 = bms_instance->rx_buf[4 + i * 7];



 	         bq79600_construct_command(bms_instance, STACK_READ, 0,  FAULT_UV2, 1, NULL); // DEV_STAT READ.
 	         bq79600_tx(bms_instance);
 	         bq79600_bsp_ready(bms_instance);
 	         for (int i = 0; i < N_DEVICES - 1; i++)
 	         modules[i].UV_RAW_2 = bms_instance->rx_buf[4 + i * 7];


 	         bq79600_construct_command(bms_instance, STACK_READ, 0,  FAULT_OV1, 1, NULL); // DEV_STAT READ.
 	         bq79600_tx(bms_instance);
 	         bq79600_bsp_ready(bms_instance);
 	         for (int i = 0; i < N_DEVICES - 1; i++)
 	         modules[i].OV_RAW_1 = bms_instance->rx_buf[4 + i * 7];



 	         bq79600_construct_command(bms_instance, STACK_READ, 0,  FAULT_OV2, 1, NULL); //
 	         bq79600_tx(bms_instance);
 	         bq79600_bsp_ready(bms_instance);
 	         for (int i = 0; i < N_DEVICES - 1; i++)
 	         modules[i].OV_RAW_2 = bms_instance->rx_buf[4 + i * 7];

 	         bq79600_construct_command(bms_instance, STACK_READ, 0,  FAULT_UT, 1, NULL); //
 	         bq79600_tx(bms_instance);
 	         bq79600_bsp_ready(bms_instance);
 	         for (int i = 0; i < N_DEVICES - 1; i++)
 	         modules[i].UT_RAW = bms_instance->rx_buf[4 + i * 7];

 	         bq79600_construct_command(bms_instance, STACK_READ, 0,  FAULT_OT, 1, NULL); //
 	         bq79600_tx(bms_instance);
 	         bq79600_bsp_ready(bms_instance);
 	         for (int i = 0; i < N_DEVICES - 1; i++)
 	         modules[i].OT_RAW = bms_instance->rx_buf[4 + i * 7];

 	        	switch(data_in)
 	        	{
 	        	case 1:
	 	        	buf = 0x3; // fault detection off, autoballancing on, ballgo = 1
	 	            bq79600_construct_command(bms_instance, STACK_WRITE, 0, BAL_CTRL2, 1, &buf);
	 	        	bq79600_tx(bms_instance);
	 	        	break;
 	        	case 2:
	 	        	buf = 0x40;
	 	            bq79600_construct_command(bms_instance, STACK_WRITE, 0, BAL_CTRL2, 1, &buf);
	 	        	bq79600_tx(bms_instance);
	 	        	break;
 	        	case 3:
	 	        	buf = 0x3;
	 	            bq79600_construct_command(bms_instance, STACK_WRITE, 0, CONTROL1, 1, &buf); // send soft restart up the stack
	 	        	bq79600_tx(bms_instance);
	 	        	//BQ_INNIT(bms_instance);
	 	        	data_in =0;
 	        		break;
 	        	}




 	         // end of reading data from BQ79600
 	         for (int i = 0; i < N_DEVICES - 1; i++) // send data from bq to different tasks.
 	         {
             if(modules[i].dietemp > 150 || modules[i].dietemp < 5) // redundancy, if the comm with bq failes, initalize it again!
             {
            	 initalize_communication(bms_instance,&huart4,N_DEVICES,N_CELLS_PER_DEVICE);
            	 break;
             }
             BqMeasurements[i].BQ_Number = i ;
 		     for (int j = 0; j < N_CELLS_PER_DEVICE; j++)
 		     {
 		     BqMeasurements[i].Bq_Voltages[j] = modules[i].vcells[j];

 		    BqMeasurements[i].Bq_Temperatures[j] = modules[i].temperature[j];
 		     }
 		    BqMeasurements[i].dietemp =  modules[i].dietemp;
 		    BqMeasurements[i].Bq_Timestamp = modules[i].timestamp;
 		    BqMeasurements[i].T_ref = modules[i].t_ref;

 		   //  uint8_t dev_stat =   bms_instance->rx_buf[4 + i * 7];
 		     BqMeasurements[i].Device_Stat.MAIN_ADC_RUN = (modules[i].DEV_STAT_RAW >> 0) & 0x01;
 		     BqMeasurements[i].Device_Stat.AUX_ADC_RUN = (modules[i].DEV_STAT_RAW >> 1) & 0x01;
 		     BqMeasurements[i].Device_Stat.CS_RUN = (modules[i].DEV_STAT_RAW >> 2) & 0x01;
 		     BqMeasurements[i].Device_Stat.OVUV_RUN = (modules[i].DEV_STAT_RAW >> 3) & 0x01;
 		     BqMeasurements[i].Device_Stat.OTUT_RUN = (modules[i].DEV_STAT_RAW >> 4) & 0x01;

 		     BqMeasurements[i].CB_DONE = (modules[i].BAL_STAT_RAW >> 0) & 0x01;
 		     BqMeasurements[i].MB_DONE = (modules[i].BAL_STAT_RAW >> 1) & 0x01;
 		     BqMeasurements[i].ABORTFLT = (modules[i].BAL_STAT_RAW >> 2) & 0x01;
 		     BqMeasurements[i].CB_RUN = (modules[i].BAL_STAT_RAW >> 3) & 0x01;
 		     BqMeasurements[i].MB_RUN = (modules[i].BAL_STAT_RAW >> 4) & 0x01;
 		     BqMeasurements[i].CB_INPAUSE = (modules[i].BAL_STAT_RAW >> 5) & 0x01;
 		     BqMeasurements[i].OT_PAUSE_DET = (modules[i].BAL_STAT_RAW >> 6) & 0x01;
 		     BqMeasurements[i].INVALID_CBCONF = (modules[i].BAL_STAT_RAW >> 7) & 0x01;

 		    for(int x = 0 ; x < 8  ; x++)
 		    {
 		    	BqMeasurements[i].OT_ERROR[x] = (modules[i].UT_RAW >> x  ) & 0x01;
 		    	BqMeasurements[i].UT_ERROR[x] = (modules[i].OT_RAW >> x  ) & 0x01;
 		    }
 		     for(int x = 0 ; x < N_CELLS_PER_DEVICE - 8  ; x++)
 		     {
 		    	BqMeasurements[i].UV_ERROR[x+8] = (modules[i].UV_RAW_2 >> x  ) & 0x01;
 		    	BqMeasurements[i].OV_ERROR[x+8] = (modules[i].OV_RAW_2 >> x  ) & 0x01;
 		    	BqMeasurements[i].CB_Done[x+8] = (modules[i].CB_COMPLETE1_RAW >> x  ) & 0x01;

 		     }
 		     for(int x = 0 ; x < 8 ; x++)
 		     {
 		    	BqMeasurements[i].UV_ERROR[x] = (modules[i].UV_RAW_1 >> (x) ) & 0x01;
 		    	BqMeasurements[i].OV_ERROR[x] = (modules[i].OV_RAW_1 >> (x) ) & 0x01;
 		    	BqMeasurements[i].CB_Done[x] = (modules[i].CB_COMPLETE2_RAW >> (x) ) & 0x01;
 		     }
 	         }


     }
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

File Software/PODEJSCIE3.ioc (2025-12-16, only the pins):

Mcu.UserName=STM32H742VITx
PA0.Signal=UART4_TX
PA1.Signal=UART4_RX
PA11.Signal=USB_OTG_FS_DM
PA12.Signal=USB_OTG_FS_DP
PA5.Signal=GPIO_Output
PB10.Signal=GPIO_Input
PB11.Signal=GPIO_Input
PB14.Signal=USB_OTG_HS_DM
PB15.Signal=USB_OTG_HS_DP
PC4.Signal=ADCx_INP4
PC7.Signal=GPIO_Output
PC8.Signal=GPIO_Output
PD0.Signal=FDCAN1_RX
PD1.Signal=FDCAN1_TX
PE14.Signal=GPIO_Input
PE15.Signal=GPIO_Input
PE2.Signal=GPIO_Output
PE3.Signal=GPIO_Output
PE4.Signal=GPIO_Output
PE5.Signal=GPIO_Output

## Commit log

2025-03-21 zmiany w bq79614 layout
    [BMS.kicad_pcb, Battery_0-12.kicad_sch, Mesurements_LTC1.kicad_sch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]
2025-03-24 zmiana polozenia zlacza oraz ukladu bq, jak i zmiena via na thru
    [BMS.kicad_pcb]
2025-04-01 Dodano layout drugiego bq79614, ukladu tlumaczącego z protokułu TI na UART oraz wstępnie poprowadzono pary różnicowe
    [5V_sch.kicad_sch, BMS.kicad_pcb, BMS.kicad_sch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]
2025-04-04 Iteracja 1.0 gotowa, teraz sprawdzenie i zmiany kosmetyczne
    [5V_sch.kicad_sch, BMS.kicad_pcb, BMS.kicad_sch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]
2025-04-08 Zmienione kondensatory na kondensatory bezpieczeństwa,poprawiono strefy na thermal relief oraz naprawiono bledy z tym zwiazane, impedancja do zmiany jeszcze
    [BMS.kicad_pcb, S252B222K502CT.stp, galvanic_isulation_0.kicad_sch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]
2025-04-10 Zmieniono złącza, zmieniono kondensatory na kondensatory bezpieczeństwa, poprawiono masę oraz dodano podział na hardware i software
    [147873-2.stp, 5V_sch.kicad_sch, BMS.kicad_pcb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]
2025-04-11 Dodano diody TVS na każdej części zasilania, zmieniono bezpieczniki, podzielono bezpieczniki na bezpieczniki do prądów wewnętrznych oraz zewnętrznych,poprawiono małe błedy
    [5V_sch.kicad_sch, BMS.kicad_pcb, Battery_0-12.kicad_sch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]
2025-04-12 Dodano wyjaśnienia w schemacie, zmieniono nazewnictwo wewnętrzne lini can
    [BMS.kicad_pcb, BMS.kicad_sch, Battery2.kicad_sch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]
2025-04-13 dodano pozostale datasheety, zmieniono blad w usb
    [BMS.kicad_pcb, Connectivity.kicad_sch, Mesurements_LTC1.kicad_sch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]
2025-04-13 to samo
    [Power_3.3V.kicad_sch]
2025-04-22 Zmiany wizualne na płytce, poprawiono ulozenie elementow na masce dekoracyjnej
    [BMS.kicad_pcb, Connectivity.kicad_sch, TPSM863253RDXR.stp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]
2025-04-25 Wiecej zmian wizualnych pod produkcje
    [5V_sch.kicad_sch, BMS.kicad_pcb, Connectivity.kicad_sch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]
2025-04-27 poprawiono impedancje na lini usb na 89ohm ( w zakresie)
    [BMS.kicad_pcb]
2025-04-27 poprawiono impedancje na sciezkach sygnalowych miedzy ukladami bq
    [BMS.kicad_pcb]
2025-04-27 Wersja V1.0 gotowa, wysłana do produckji
    [BMS.kicad_pcb, Mesurements_LTC1.kicad_sch, Mesurements_LTC2.kicad_sch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]
2025-05-06 Male zmiany
    [BMS.kicad_pcb, Connectivity.kicad_sch, Mesurements_LTC1.kicad_sch]
2025-05-20 Fixed boot resistor ground
    [BMS.kicad_pcb]
2025-07-15 zmiany w kodzier bq
    [5V_sch.kicad_sch, BMS.kicad_pcb, BMS.kicad_sch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]
2025-08-05 Po 2 miesiącach walki pierwszy działający kod do BMS'A, odczyt napięc działa, over/under voltage protection w trakcie testów
2025-08-14 Dodano wysyłanie danych do komputera na usb za pomocą portu szeregowego, podstawy pod pomiary temperatur
2025-08-24 Pomiary temperatury nie sparwne, pomiar temperatur BQ79614 poprawny, krytyczne jest odpowiednie opoźnienie odczytów
2025-08-25 W pełni działające OV oraz UV obliczane w bq79614 a nie w stm32
2025-09-02 Dodano podstawy komunikacji CAN , nie przeprowadzono jescze weryfikacji działania kodu
    [Mesurements_LTC1.kicad_sch, Mesurements_LTC2.kicad_sch]
2025-09-09 Dodano działające pomiary temperatury bazujące na regresji liniowej symulowanych pomiarów
2025-11-16 Poprawiono impedancje lini can
    [BMS.kicad_pcb]
2025-11-22 Dodano logikę ładowania bateri, zabezpieczenia OV UV na przekaźniku działają poprawnie, przekaźnik ma swój test polegający na styku pomocniczym
    [BMS.kicad_pcb, BMS.kicad_sch]
2026-01-03 Zmiany wizualne w schemacie
    [BMS.kicad_sch, Mesurements_LTC1.kicad_sch, Power.kicad_sch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]

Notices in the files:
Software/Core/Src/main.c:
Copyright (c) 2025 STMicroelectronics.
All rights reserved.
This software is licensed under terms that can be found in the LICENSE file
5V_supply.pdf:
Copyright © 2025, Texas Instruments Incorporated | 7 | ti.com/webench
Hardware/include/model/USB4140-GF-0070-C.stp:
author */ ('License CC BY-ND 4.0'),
